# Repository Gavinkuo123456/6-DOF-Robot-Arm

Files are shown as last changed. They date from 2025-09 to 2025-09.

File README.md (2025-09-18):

# Cost-Effective 6 DOF robotic arm

A cost-effective 6-degree-of-freedom robotic arm offering both precision and a strong load capacity for its price range.

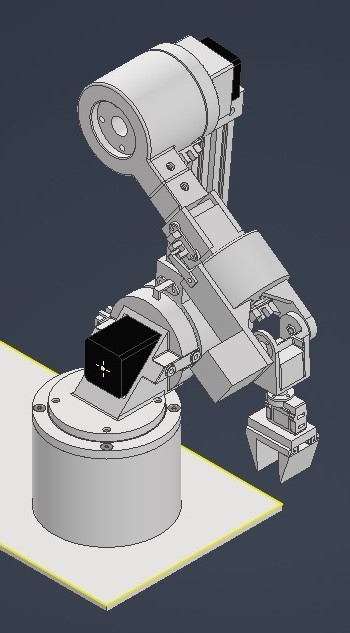
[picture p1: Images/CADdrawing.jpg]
Robot Arm CAD


## 🤖 Overview

This project features a fully functional 6-DOF robotic arm that combines:
- **3D printed mechanical components** for cost-effective construction
- **Stepper motor actuation** for precise positioning
- **Powerfull motor controller** for driving high-torque motors with precise control
- **Arduino-based control system** for accessibility and expandability
- **Open-loop control** for simplicity, reliability and easy maintenance

## ✨ Features

- **6 Degrees of Freedom**: Full spatial movement capability
- **Stepper Motor Control**: Precise angular positioning
- **3D Printable Design**: Accessible manufacturing with standard FDM printers
- **Arduino Compatible**: Easy programming and customization
- **Open Source**: Complete design files and code available
- **standard hardware**: Easy assembly and easy to find online

## 📋 Specifications

| Parameter | Value |
|---|---|
| Degrees of Freedom | 6 |
| Motor Type | Stepper Motors |
| Control System | Arduino-based |
| Control Method | Open-loop |
| Construction | 3D Printed + Hardware |
| Workspace | ? |
| Payload Capacity | ? |
| Repeatability | ✅ |

## 🛠️ Hardware Requirements

### Electronics
- **Arduino Board** Arduino mega 2560
- **Stepper Motor Drivers** TMC2209 × 3 , LM542 x 3
- **Stepper Motors**
   - **Joint 1** NEMA23x56
   - **Joint 2** NEMA17x60 with 1:50 planetary gearbox
   - **Joint 3** NEMA17x48 with 1:27 planetary gearbox
   - **Joint 4** NEMA11x34 with 1:20 planetary gearbox
   - **Joint 5** NEMA 14x40
   - **Joint 6** NEMA11x34
- **Power Supply** 24V 50W
- **Jumper Wires** and **Breadboard/PCB**
- **Limit Switches** optical endstop x 6

# WIP below

### Mechanical Components
- **3D Printed Parts** (see `/mechanical` folder)
- **Bearings** (608ZZ or similar)
- **Screws and Fasteners** (M3, M4, M5 bolts and nuts)
- **Timing Belts and Pulleys** (GT2)
- **Linear Rods** (8mm diameter)

### Tools Required
- 3D Printer (FDM, 200×200×200mm minimum build volume)
- Screwdrivers
- Allen keys/Hex keys
- Wire strippers
- Multimeter

## 🔧 Assembly Instructions

### 1. 3D Printing
1. Print all parts from the `/mechanical/stl` folder
2. Recommended print settings:
   - Layer Height: 0.2mm
   - Infill: 20-30%
   - Support: As needed
   - Material: PLA or PETG

### 2. Electronics Assembly
1. Connect stepper motor drivers to Arduino
2. Wire stepper motors to drivers
3. Connect power supply (ensure proper current ratings)
4. Add limit switches if using homing functionality

### 3. Mechanical Assembly
1. Assemble the base joint (Joint 1)
2. Install shoulder joint (Joint 2)
3. Attach upper arm assembly (Joint 3)
4. Mount forearm assembly (Joint 4)
5. Install wrist joints (Joints 5 & 6)
6. Attach end effector mount

Detailed assembly instructions with images available in `/docs/assembly.md`

## 💻 Software Setup

### Prerequisites
- Arduino IDE (latest version)
- Required Libraries:
  - `AccelStepper`
  - `MultiStepper`
  - `Servo` (if using servo gripper)

### Installation
1. Clone this repository:
   ```bash
   git clone https://github.com/Gavinkuo123456/6-DOF-Robot-Arm.git
   cd 6-DOF-Robot-Arm
   ```

2. Open the main Arduino sketch:
   ```
   /arduino/robot_arm_control/robot_arm_control.ino
   ```

3. Install required libraries through Arduino IDE Library Manager

4. Upload the code to your Arduino board

### Configuration
1. Adjust motor parameters in `config.h`
2. Calibrate joint limits and step ratios
3. Set communication baud rate (default: 115200)

## 🎮 Usage

### Basic Control
The robot arm can be controlled through:
- **Serial Commands**: Send position commands via serial monitor
- **G-code**: Basic G-code interpreter for coordinated movements
- **Python Interface**: Use provided Python scripts for advanced control

### Command Examples
```
// Move to joint positions (degrees)
J 45 30 -20 0 45 90

// Move to Cartesian position (mm)
P 200 150 100 0 90 0

// Home all joints
H

// Emergency stop
STOP
```

### Python Control Example
```python
import serial
import time

# Connect to Arduino
arm = serial.Serial('/dev/ttyUSB0', 115200)
time.sleep(2)

# Move to position
arm.write(b'J 0 45 -30 0 45 0\n')
time.sleep(3)

arm.close()
```

## 📊 Kinematics

The robot arm uses standard Denavit-Hartenberg parameters for kinematic calculations. Forward and inverse kinematics algorithms are implemented for position control.

### Joint Configuration
- **Joint 1**: Base rotation (±180°)
- **Joint 2**: Shoulder pitch (±90°)
- **Joint 3**: Elbow pitch (±135°)
- **Joint 4**: Wrist roll (±180°)
- **Joint 5**: Wrist pitch (±90°)
- **Joint 6**: Wrist yaw (±180°)

## 📁 Project Structure

```
6-DOF-Robot-Arm/
├── arduino/                 # Arduino code
│   ├── robot_arm_control/   # Main control sketch
│   ├── libraries/           # Custom libraries
│   └── examples/            # Example sketches
├── mechanical/              # 3D models and drawings
│   ├── stl/                # STL files for printing
│   ├── cad/                # Original CAD files
│   └── assembly/           # Assembly drawings
├── software/               # PC software and utilities
│   ├── python/             # Python control scripts
│   ├── matlab/             # MATLAB simulation
│   └── gui/                # Graphical interface
├── docs/                   # Documentation
│   ├── assembly.md         # Assembly instructions
│   ├── calibration.md      # Calibration guide
│   └── troubleshooting.md  # Common issues
├── images/                 # Project images
└── README.md              # This file
```

## 🔍 Troubleshooting

### Common Issues
1. **Motors not moving**: Check wiring and power supply
2. **Inaccurate positioning**: Calibrate steps per degree
3. **Communication errors**: Verify baud rate and connections
4. **Mechanical binding**: Check assembly and lubrication

See `/docs/troubleshooting.md` for detailed solutions.

## 🚀 Future Enhancements

- [ ] Closed-loop control with encoders
- [ ] Vision system integration
- [ ] ROS compatibility
- [ ] Mobile app control
- [ ] Advanced path planning
- [ ] Machine learning integration
- [ ] Multi-arm coordination

## 🤝 Contributing

Contributions are welcome! Please feel free to submit pull requests, report bugs, or suggest improvements.

1. Fork the repository
2. Create a feature branch (`git checkout -b feature/amazing-feature`)
3. Commit your changes (`git commit -m 'Add some amazing feature'`)
4. Push to the branch (`git push origin feature/amazing-feature`)
5. Open a Pull Request

## 📝 License

This project is licensed under the MIT License - see the [LICENSE](LICENSE) file for details.

## 👨‍💻 Author

**Gavin Kuo** - [Gavinkuo123456](https://github.com/Gavinkuo123456)

## 🙏 Acknowledgments

- Arduino community for libraries and support
- 3D printing community for design inspiration
- Robotics researchers for kinematic algorithms
- Open-source contributors

## 📞 Support

If you have questions or need help:
- Open an [Issue](https://github.com/Gavinkuo123456/6-DOF-Robot-Arm/issues)
- Check the [Documentation](./docs/)
- Join the discussion in [Discussions](https://github.com/Gavinkuo123456/6-DOF-Robot-Arm/discussions)

---

**⭐ Star this repository if you find it helpful!**




Made with ❤️ for the robotics community

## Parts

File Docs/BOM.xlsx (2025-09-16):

名稱 | 數量 | 價格 | 網址 |  | 列印件 | 重量(g) | 列印時間
平面軸承12cm | 1 | 358 | https://www.ruten.com.tw/item/show?22412077561142 |  | 關節一基座 | 168.75 | 11:57:00
57x56mm步進馬達 | 1 | 540 | https://www.ruten.com.tw/item/show?22446200583860 |  | 關節二基座 | 88 | 5:40:00
42x60mm步進馬達1:50減速機 | 1 | 811 | https://www.ruten.com.tw/item/show?22449367276945 |  | 關節二移動件 | 77 | 5:10:00
6009軸承 | 2 | 532 | https://www.ruten.com.tw/item/show?22513075948398 |  | 關節三基座 | 65 | 4:53:00
Z21-內徑8*外徑18脹緊套 | 2 | 482 | https://www.ruten.com.tw/item/show?22527034233935 |  | 關節三移動件 | 82 | 5:17:00
42x48mm步進馬達1:27減速機 | 1 | 631 | https://www.ruten.com.tw/item/show?22449367276945 |  | 關節四基座 | 30 | 2:31:00
28x33步進馬達1:20減速機 | 1 | 680 | https://www.ruten.com.tw/item/show?22449367276945 |  | 關節四馬達蓋 | 8 | 0:00:00
圓法蘭18mm | 2 | 316 | https://www.ruten.com.tw/item/show?22511904533779 |  | 關節四移動件(五基座) | 51 | 4:07:00
28x34mm步進馬達 | 1 | 584 | https://www.ruten.com.tw/item/show?22529233061690 |  | 關節六基座 | 10 | 0:58:00
6007軸承 | 1 | 146 | https://www.ruten.com.tw/item/show?22513075948398 |  | 夾爪基座 | 4 | 0:31:00
5mm聯軸器 | 1 | 50 | https://www.ruten.com.tw/item/show?21822082042595 |  | 夾爪滑槽 | 7.5 | 1:00:00
35x40mm步進馬達 | 1 | 261 | https://www.ruten.com.tw/item/show?22534632849356 |  | 夾爪手指 | 6.6 | 0:46:00
MG90S伺服馬達 | 1 | 70 |  | 光華 | 夾爪齒輪 | 0.76 | 0:06:00
光學限位開關 | 6 | 216 | https://www.ruten.com.tw/item/show?22534602360418
LM542步進驅動器(大馬達用) | 3 | 1173 | https://www.ruten.com.tw/item/show?22324952210619
Arduino Mega2560 | 1 | 508 | https://www.ruten.com.tw/item/show?22422643706143
TMC2209步進驅動器(小馬達用) | 3 | 444 | https://www.ruten.com.tw/item/show?22326111341624
CNC shield | 1 | 46 | https://www.ruten.com.tw/item/show?22412100171865
萬用板 | 1 |  |  | 光華
杜邦排針 | 數排 |  |  | 光華
杜邦裸線 | 四種顏色數條 |  |  | 光華
杜邦4pin接頭 | 數個 |  |  | 光華
M5螺絲+羅母 | 大量 |  | https://www.ruten.com.tw/store/goodsforyou2014/
M4螺絲+羅母 | 大量 |  | https://www.ruten.com.tw/store/goodsforyou2014/ |  |  | 598.61
M3螺絲+羅母 | 大量 |  | https://www.ruten.com.tw/store/goodsforyou2014/
鋁擠型2020 | 三根
 |  | 7848

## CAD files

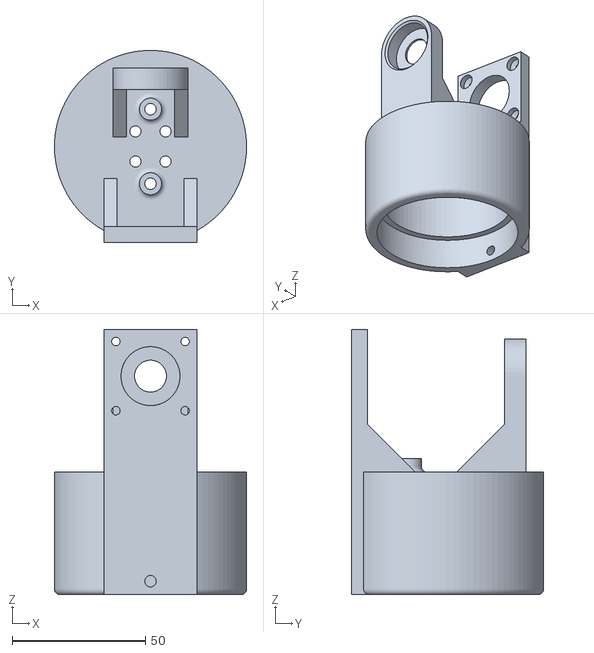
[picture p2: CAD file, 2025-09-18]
3D-model/3D print and Laser cut file/j4 moving part.stl
72.1 x 72.1 x 99.5

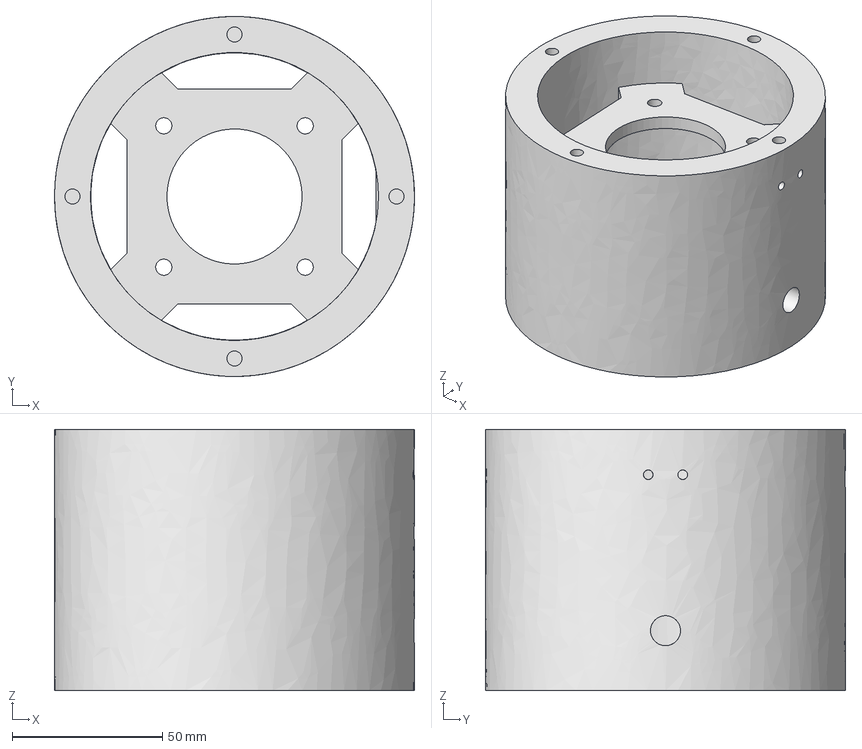
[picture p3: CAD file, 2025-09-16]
3D-model/robot armT 2(CAD file)/j1 57 mount CNC.igs
120.0 x 120.0 x 87.1 mm

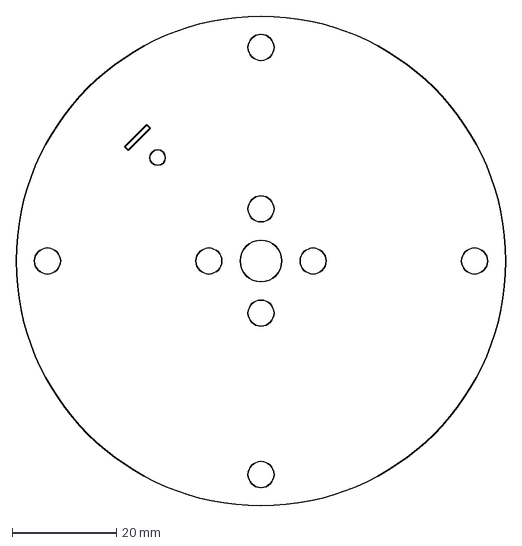
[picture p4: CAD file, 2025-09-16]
3D-model/robot armT 2/3dp/j1 plate lz.dxf
94.0 x 94.0 mm

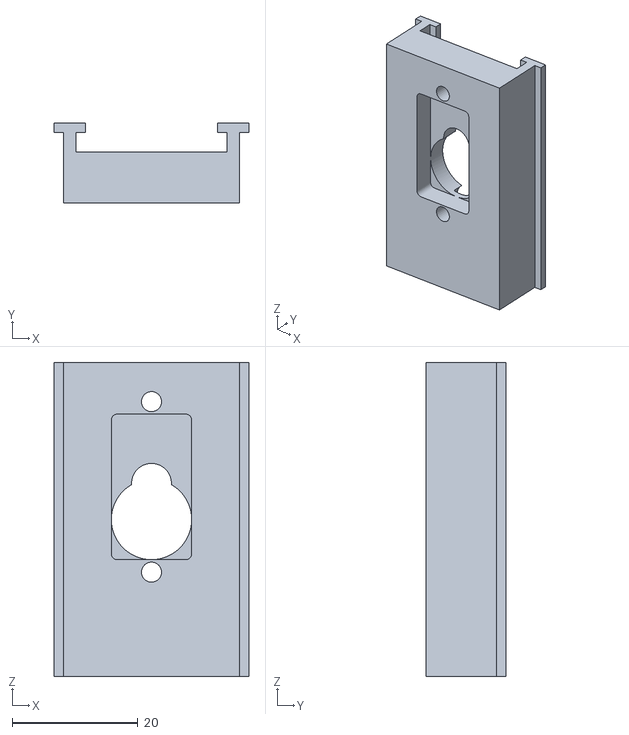
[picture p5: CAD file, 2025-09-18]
3D-model/3D print and Laser cut file/sg90 claw mount.stl
31.0 x 12.7 x 50.0

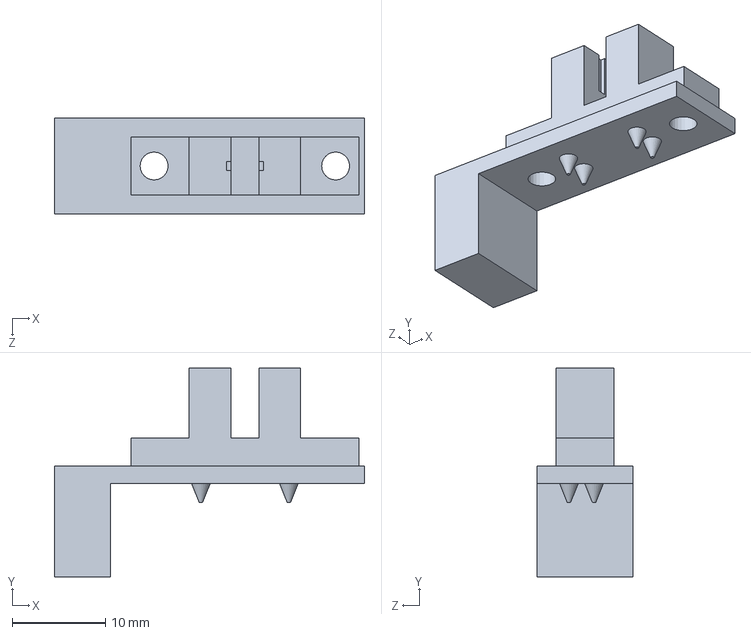
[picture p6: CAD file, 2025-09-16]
3D-model/robot armT 2(CAD file)/optik_limit_switch.SLDPRT
33.3 x 22.4 x 10.3 mm

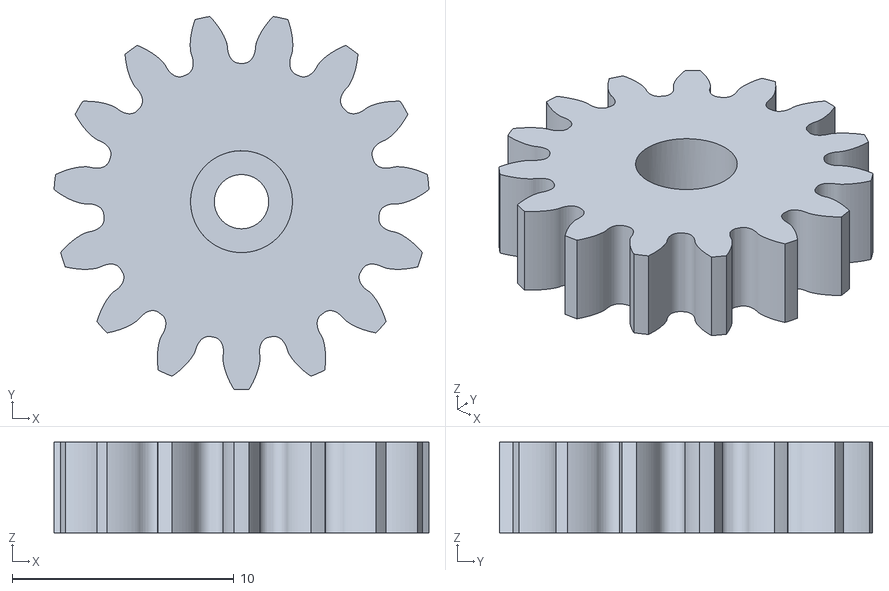
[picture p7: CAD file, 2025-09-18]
3D-model/3D print and Laser cut file/sg90 claw gear m1.stl
16.9 x 16.8 x 4.10

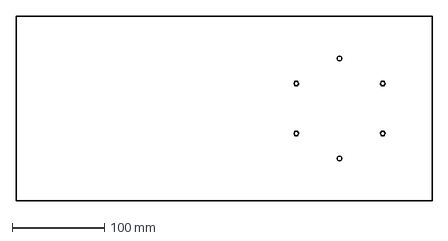
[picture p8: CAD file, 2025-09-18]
3D-model/3D print and Laser cut file/base plate laser cut.dxf
450.0 x 200.0 mm

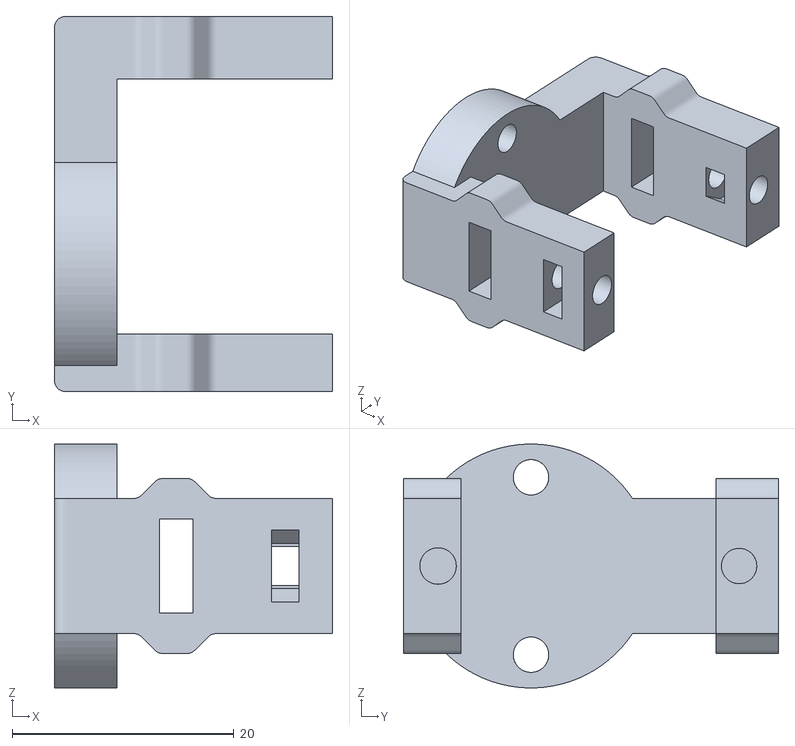
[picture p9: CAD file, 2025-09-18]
3D-model/3D print and Laser cut file/sg90 claw v2 conector.stl
25.1 x 33.8 x 22.0

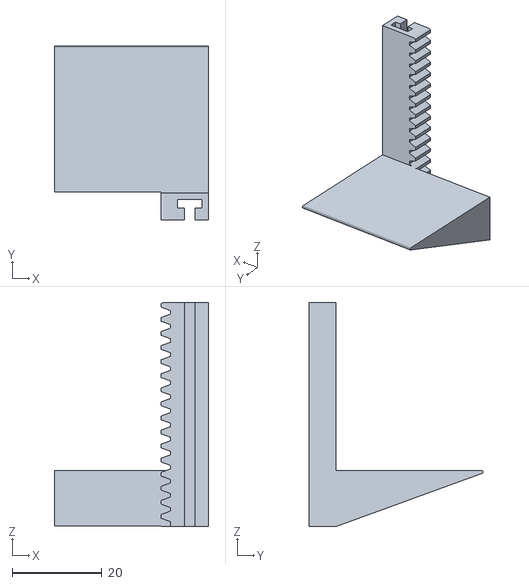
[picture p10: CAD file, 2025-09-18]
3D-model/3D print and Laser cut file/sg90 claw finger long.stl
34.4 x 38.9 x 50.0

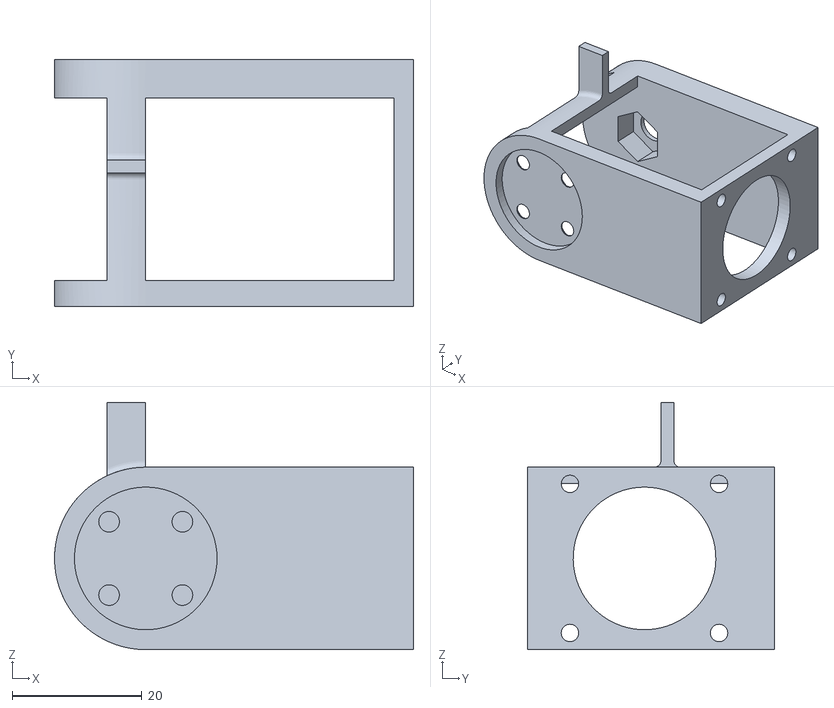
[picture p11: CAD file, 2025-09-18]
3D-model/3D print and Laser cut file/j6 motor mount .stl
55.4 x 38.2 x 38.2

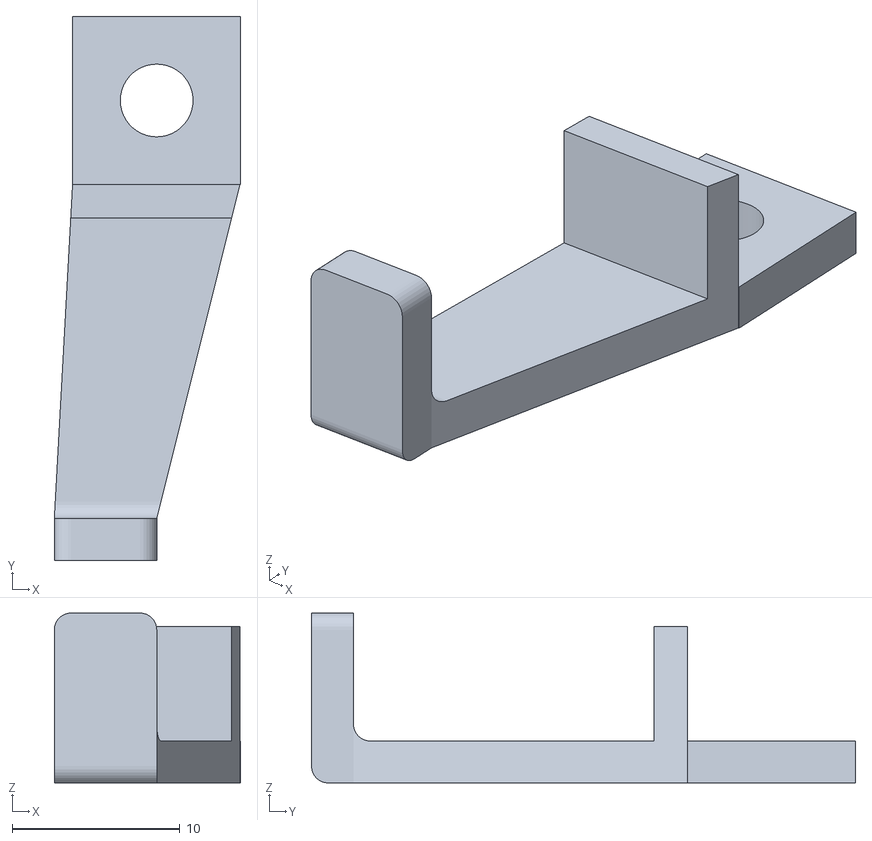
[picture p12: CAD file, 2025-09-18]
3D-model/3D print and Laser cut file/j4 endstop blocker.stl
11.1 x 32.4 x 10.1

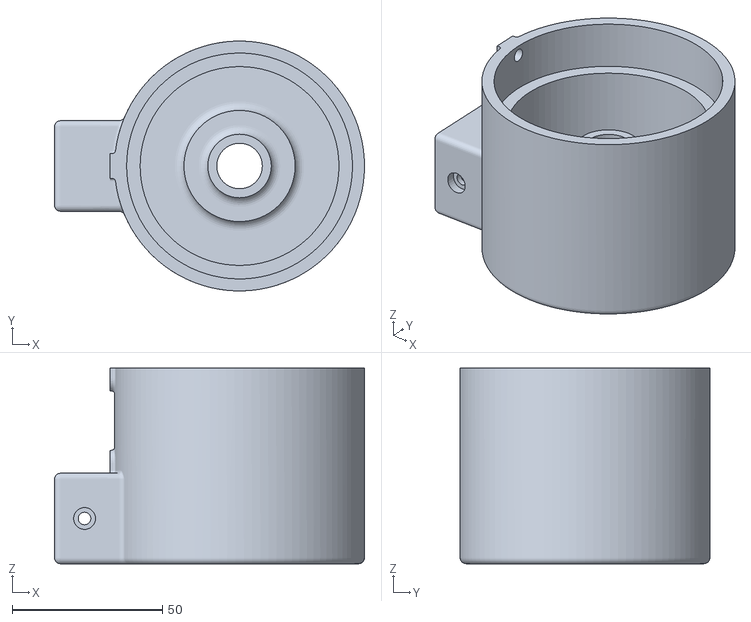
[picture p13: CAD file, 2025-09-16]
3D-model/3D print and Laser cut file/j3 moving part.stl
103.2 x 83.1 x 65.1

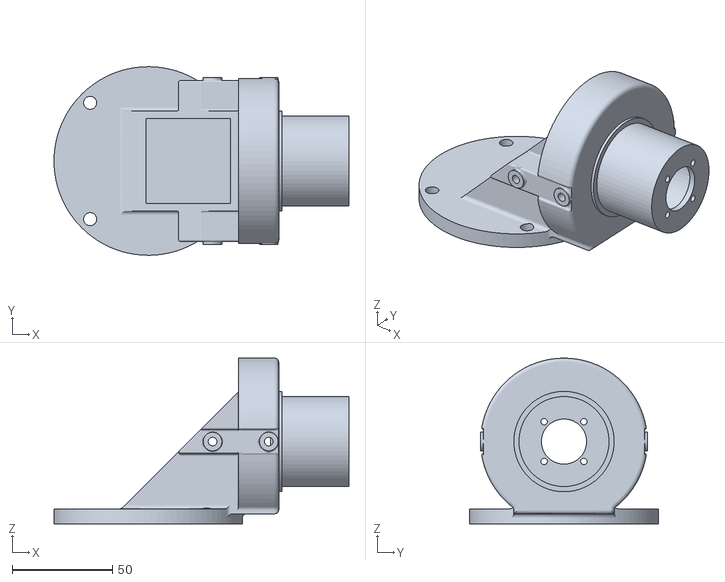
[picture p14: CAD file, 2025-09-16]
3D-model/3D print and Laser cut file/j2 42 motor mount.stl
147.0 x 94.0 x 82.5

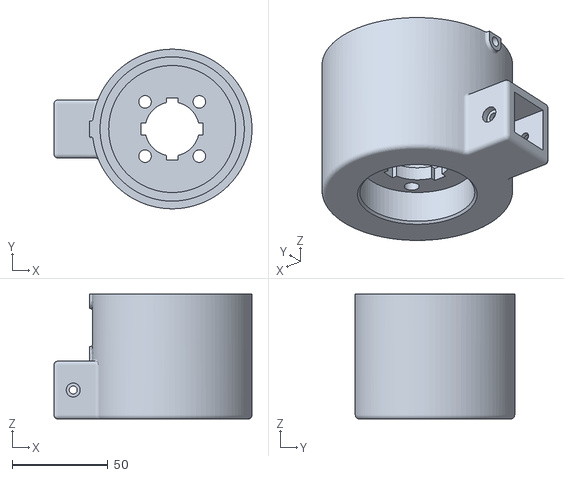
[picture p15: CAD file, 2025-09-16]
3D-model/3D print and Laser cut file/j3 moving part option3.stl
103.2 x 83.1 x 65.1

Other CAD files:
3D-model/3D print and Laser cut file/j2 moving part option2.stl
3D-model/3D print and Laser cut file/j3 endstop blocker.stl
3D-model/3D print and Laser cut file/j2 endstop blocker.stl
3D-model/3D print and Laser cut file/j4 motor mount.stl
3D-model/3D print and Laser cut file/j1 57 mount.stl
3D-model/3D print and Laser cut file/j1 endstop block v2.stl
3D-model/3D print and Laser cut file/j4 motor mount cover.stl
3D-model/robot armT 2(CAD file)/18mm hub.ipt
3D-model/robot armT 2(CAD file)/28stepper27.ipt
3D-model/robot armT 2(CAD file)/35x40 stepper.ipt
3D-model/robot armT 2(CAD file)/5mm axle hub.ipt
3D-model/robot armT 2(CAD file)/6mm axle hub.ipt
3D-model/robot armT 2(CAD file)/8 mm hub.ipt
3D-model/robot armT 2(CAD file)/8mm axle mount.ipt
3D-model/robot armT 2(CAD file)/9G Servo Motor SG90.ipt
3D-model/robot armT 2(CAD file)/BS 4168 - M5 x 16(7).ipt
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

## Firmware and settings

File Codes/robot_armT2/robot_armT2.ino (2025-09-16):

#include <Wire.h>
#include <Servo.h>
#include <AccelStepper.h>
#include <math.h>

// Define stepper pins
#define ASTEP_PIN 48  // Step pin
#define ADIR_PIN 50   // Direction pin
#define AENABLE 52
#define BSTEP_PIN 44  // Step pin
#define BDIR_PIN 46   // Direction pin
#define CSTEP_PIN 40  // Step pin
#define CDIR_PIN 42   // Direction pin
#define DSTEP_PIN 2   // Step pin
#define DDIR_PIN 5    // Direction pin
#define ESTEP_PIN 3   // Step pin
#define EDIR_PIN 6
#define FSTEP_PIN 4
#define FDIR_PIN 7
#define ENABLE 8

#define Aendstop 43
#define Bendstop 41
#define Cendstop 39
#define Dendstop 37
#define Eendstop 35
#define emergbtn 53

const int SLAVE_ADDRESS = 1;
char incomingByte = 0;
char ji2cindex;
bool i2cIN = 0;

String i2cC = "";

float alocation = 0;
float blocation = 0;
float clocation = 0;
float dlocation = 0;
float elocation = 0;
float flocation = 0;
float clawlocation = 0;

const float agear = 1;
const float bgear = 50;
const float cgear = 27;
const float dgear = 20;
const float egear = 1;
const float fgear = 1;
const float steppower = 4.4;  // 1/(360/steps/rev)
const float radtoang = 57.295;


// Steps per revolution for the motor
const float speed = 900;
const float maxspeed = 800;

const float accel = 500;
const float stepsPerRevolution = 1600;
// Microstepping multiplier (1, 2, 4, 8, 16, or 32)

// AccelStepper instance in driver mode
AccelStepper stepperA(AccelStepper::DRIVER, ASTEP_PIN, ADIR_PIN);
AccelStepper stepperB(AccelStepper::DRIVER, BSTEP_PIN, BDIR_PIN);
AccelStepper stepperC(AccelStepper::DRIVER, CSTEP_PIN, CDIR_PIN);
AccelStepper stepperD(AccelStepper::DRIVER, DSTEP_PIN, DDIR_PIN);
AccelStepper stepperE(AccelStepper::DRIVER, ESTEP_PIN, EDIR_PIN);
AccelStepper stepperF(AccelStepper::DRIVER, FSTEP_PIN, FDIR_PIN);
Servo claw;

static const int DOF = 6;
static const float alpha_[DOF] = { -1.57f, 0.00f, 1.57f, -1.57f, 1.57f, 0.00f };     // radians
static const float a_[DOF] = { 0.000f, 252.625f, 0.000f, 0.000f, 0.000f, 0.000f };   // mm
static const float d_[DOF] = { 136.1f, 0.0f, 0.0f, 214.6f, 0.0f, 129.471f };         // mm
static const float theta_off_[DOF] = { 0.00f, -1.57f, 1.57f, 0.00f, 0.00f, 0.00f };  // radians

// IK settings
static const int MAX_ITERS = 120;     // iterations cap
static const float DAMPING = 0.02f;   // lambda for DLS (radians & mm units)
static const float POS_TOL = 0.5f;    // mm
static const float ROT_TOL = 0.005f;  // rad (~0.29 deg)
// ---------------------------------------------------------------------------------
// Math helpers
// ---------------------------------------------------------------------------------
struct Vec3 {
  float x, y, z;
};

static inline float clampf(float x, float lo, float hi) {
  return x < lo ? lo : (x > hi ? hi : x);
}

static inline void mat4Mul(const float A[16], const float B[16], float C[16]) {
  for (int r = 0; r < 4; r++) {
    for (int c = 0; c < 4; c++) {
      float s = 0;
      for (int k = 0; k < 4; k++) s += A[r * 4 + k] * B[k * 4 + c];
      C[r * 4 + c] = s;
    }
  }
}

static inline void mat4Copy(const float S[16], float D[16]) {
  for (int i = 0; i < 16; i++) D[i] = S[i];
}

static inline void mat4FromDH(float a, float alpha, float d, float theta, float T[16]) {
  float ct = cosf(theta), st = sinf(theta);
  float ca = cosf(alpha), sa = sinf(alpha);
  T[0] = ct;
  T[1] = -st * ca;
  T[2] = st * sa;
  T[3] = a * ct;
  T[4] = st;
  T[5] = ct * ca;
  T[6] = -ct * sa;
  T[7] = a * st;
  T[8] = 0;
  T[9] = sa;
  T[10] = ca;
  T[11] = d;
  T[12] = 0;
  T[13] = 0;
  T[14] = 0;
  T[15] = 1;
}

static inline void mat4ExtractRPY_ZYX(const float T[16], float &rx, float &ry, float &rz) {
  // ZYX intrinsic (yaw Z, pitch Y, roll X). Using rotation matrix R = T[0..10].
  const float r00 = T[0], r01 = T[1], r02 = T[2];
  const float r10 = T[4], r11 = T[5], r12 = T[6];
  const float r20 = T[8], r21 = T[9], r22 = T[10];
  float pitch = asinf(-clampf(r20, -1.0f, 1.0f));
  float roll, yaw;
  if (fabsf(r20) < 0.9999f) {
    roll = atan2f(r21, r22);
    yaw = atan2f(r10, r00);
  } else {
    // Gimbal-close case: use alternative
    roll = 0.0f;
    yaw = atan2f(-r01, r11);
  }
  rx = roll;
  ry = pitch;
  rz = yaw;
}

static inline void rpyZYX_to_R(float rx, float ry, float rz, float R[9]) {
  // rx=roll(X), ry=pitch(Y), rz=yaw(Z)
  float cx = cosf(rx), sx = sinf(rx);
  float cy = cosf(ry), sy = sinf(ry);
  float cz = cosf(rz), sz = sinf(rz);
  // R = Rz(rz)*Ry(ry)*Rx(rx)
  R[0] = cz * cy;
  R[1] = cz * sy * sx - sz * cx;
  R[2] = cz * sy * cx + sz * sx;
  R[3] = sz * cy;
  R[4] = sz * sy * sx + cz * cx;
  R[5] = sz * sy * cx - cz * sx;
  R[6] = -sy;
  R[7] = cy * sx;
  R[8] = cy * cx;
}

static inline void R_to_axisAngle(const float R[9], float axis[3], float &angle) {
  float tr = R[0] + R[4] + R[8];
  float c = (tr - 1.0f) * 0.5f;
  c = clampf(c, -1.0f, 1.0f);
  angle = acosf(c);
  if (angle < 1e-6f) {
    axis[0] = axis[1] = axis[2] = 0;
    angle = 0;
    return;
  }
  float denom = 2.0f * sinf(angle);
  axis[0] = (R[7] - R[5]) / denom;
  axis[1] = (R[2] - R[6]) / denom;
  axis[2] = (R[3] - R[1]) / denom;
}

// ---------------------------------------------------------------------------------
// Forward Kinematics
// ---------------------------------------------------------------------------------
static void fk(const float q[DOF], float T[16]) {
  float Ti[16], Tacc[16];
  // Init to identity
  for (int i = 0; i < 16; i++) Tacc[i] = (i % 5 == 0) ? 1.0f : 0.0f;
  for (int i = 0; i < DOF; i++) {
    float theta = q[i] + theta_off_[i];
    mat4FromDH(a_[i], alpha_[i], d_[i], theta, Ti);
    float Tnew[16];
    mat4Mul(Tacc, Ti, Tnew);
    mat4Copy(Tnew, Tacc);
  }
  mat4Copy(Tacc, T);
}

// ---------------------------------------------------------------------------------
// Jacobian (geometric) for 6R arm
// ---------------------------------------------------------------------------------
static void jacobian(const float q[DOF], float J[6 * DOF]) {
  float Tacc[16];
  // identity
  for (int i = 0; i < 16; i++) Tacc[i] = (i % 5 == 0) ? 1.0f : 0.0f;

  float origins[DOF + 1][3];
  float zaxes[DOF + 1][3];

  // base frame
  origins[0][0] = 0;
  origins[0][1] = 0;
  origins[0][2] = 0;
  zaxes[0][0] = 0;
  zaxes[0][1] = 0;
  zaxes[0][2] = 1;

  // accumulate frames
  for (int i = 0; i < DOF; i++) {
    float Ti[16];
    float theta = q[i] + theta_off_[i];
    mat4FromDH(a_[i], alpha_[i], d_[i], theta, Ti);
    float Tnew[16];
    mat4Mul(Tacc, Ti, Tnew);
    mat4Copy(Tnew, Tacc);

    origins[i + 1][0] = Tacc[3];
    origins[i + 1][1] = Tacc[7];
    origins[i + 1][2] = Tacc[11];

    zaxes[i + 1][0] = Tacc[2];
    zaxes[i + 1][1] = Tacc[6];
    zaxes[i + 1][2] = Tacc[10];
  }

  float pe[3] = { origins[DOF][0], origins[DOF][1], origins[DOF][2] };

  for (int i = 0; i < DOF; i++) {
    float zi[3] = { zaxes[i][0], zaxes[i][1], zaxes[i][2] };
    float pi[3] = { origins[i][0], origins[i][1], origins[i][2] };
    float r[3] = { pe[0] - pi[0], pe[1] - pi[1], pe[2] - pi[2] };
    // cross(zi, r)
    float jv[3] = { zi[1] * r[2] - zi[2] * r[1], zi[2] * r[0] - zi[0] * r[2], zi[0] * r[1] - zi[1] * r[0] };

    J[0 * DOF + i] = jv[0];
    J[1 * DOF + i] = jv[1];
    J[2 * DOF + i] = jv[2];
    J[3 * DOF + i] = zi[0];
    J[4 * DOF + i] = zi[1];
    J[5 * DOF + i] = zi[2];
  }
}

// Multiply 6x6 with 6x1: y = A*x
static inline void mat6x6_mul_vec(const float A[36], const float x[6], float y[6]) {
  for (int r = 0; r < 6; r++) {
    float s = 0;
    for (int c = 0; c < 6; c++) s += A[r * 6 + c] * x[c];
    y[r] = s;
  }
}

// Build normal matrix A = J*J^T + (lambda^2) I (6x6) and compute its inverse via adjugate/Gauss-Jordan (simple, not super-optimized)
// Returns false if singular.
static bool invert6x6(const float A[36], float invA[36]) {
  // Augment [A | I] and perform Gauss-Jordan
  float M[6][12];
  for (int r = 0; r < 6; r++) {
    for (int c = 0; c < 6; c++) M[r][c] = A[r * 6 + c];
    for (int c = 0; c < 6; c++) M[r][6 + c] = (r == c) ? 1.0f : 0.0f;
  }
  for (int i = 0; i < 6; i++) {
    // pivot
    int piv = i;
    float maxA = fabsf(M[i][i]);
    for (int r = i + 1; r < 6; r++) {
      float v = fabsf(M[r][i]);
      if (v > maxA) {
        maxA = v;
        piv = r;
      }
    }
    if (maxA < 1e-8f) return false;
    if (piv != i) {
      for (int c = 0; c < 12; c++) {
        float tmp = M[i][c];
        M[i][c] = M[piv][c];
        M[piv][c] = tmp;
      }
    }
    // normalize row
    float diag = M[i][i];
    for (int c = 0; c < 12; c++) M[i][c] /= diag;
    // eliminate
    for (int r = 0; r < 6; r++)
      if (r != i) {
        float f = M[r][i];
        if (f != 0) {
          for (int c = 0; c < 12; c++) M[r][c] -= f * M[i][c];
        }
      }
  }
  // extract inv
  for (int r = 0; r < 6; r++)
    for (int c = 0; c < 6; c++) invA[r * 6 + c] = M[r][6 + c];
  return true;
}

// Compute error twist between current T(q) and desired pose (x,y,z, rpy_ZYX)
static void poseError(const float Tcurr[16], const float p_des[3], const float rpy_des[3], float e[6]) {
  // position error
  e[0] = p_des[0] - Tcurr[3];
  e[1] = p_des[1] - Tcurr[7];
  e[2] = p_des[2] - Tcurr[11];
  // orientation error via axis-angle of R_err = R_des * R_curr^T
  float Rcurr[9] = { Tcurr[0], Tcurr[1], Tcurr[2], Tcurr[4], Tcurr[5], Tcurr[6], Tcurr[8], Tcurr[9], Tcurr[10] };
  float Rdes[9];
  rpyZYX_to_R(rpy_des[0], rpy_des[1], rpy_des[2], Rdes);
  // R_err = Rdes * Rcurr^T
  float Rct[9] = { Rcurr[0], Rcurr[3], Rcurr[6], Rcurr[1], Rcurr[4], Rcurr[7], Rcurr[2], Rcurr[5], Rcurr[8] };
  float Rerr[9];
  for (int r = 0; r < 3; r++)
    for (int c = 0; c < 3; c++) {
      float s = 0;
      for (int k = 0; k < 3; k++) s += Rdes[r * 3 + k] * Rct[k * 3 + c];
      Rerr[r * 3 + c] = s;
    }
  float axis[3];
  float ang;
  R_to_axisAngle(Rerr, axis, ang);
  e[3] = axis[0] * ang;
  e[4] = axis[1] * ang;
  e[5] = axis[2] * ang;  // small-angle rotation vector
}

// Damped Least Squares IK: returns true if converged, q is updated in-place
static bool ik_solve(float q[DOF], const float p_des[3], const float rpy_des[3]) {
  for (int iter = 0; iter < MAX_ITERS; ++iter) {
    // FK and error
    float Tcurr[16];
    fk(q, Tcurr);
    float e[6];
    poseError(Tcurr, p_des, rpy_des, e);

    float pos_err = sqrtf(e[0] * e[0] + e[1] * e[1] + e[2] * e[2]);
    float rot_err = sqrtf(e[3] * e[3] + e[4] * e[4] + e[5] * e[5]);
    if (pos_err < POS_TOL && rot_err < ROT_TOL) return true;

    // Jacobian
    float J[6 * DOF];
    jacobian(q, J);

    // A = J*J^T + λ^2 I (6x6)
    float A[36] = { 0 };
    for (int r = 0; r < 6; r++) {
      for (int c = 0; c < 6; c++) {
        float s = 0;
        for (int k = 0; k < DOF; k++) s += J[r * DOF + k] * J[c * DOF + k];
        A[r * 6 + c] = s;
      }
      A[r * 6 + r] += (DAMPING * DAMPING);
    }
    float invA[36];
    if (!invert6x6(A, invA)) return false;

    // y = invA * e
    float y[6];
    mat6x6_mul_vec(invA, e, y);

    // dq = J^T * y
    float dq[DOF];
    for (int i = 0; i < DOF; i++) {
      float s = 0;
      for (int r = 0; r < 6; r++) s += J[r * DOF + i] * y[r];
      dq[i] = s;
    }

    // step size limiting (simple clipping)
    const float MAX_STEP = 0.2f;  // rad per iter (or mm-equivalent via Jacobian mapping)
    for (int i = 0; i < DOF; i++) dq[i] = clampf(dq[i], -MAX_STEP, MAX_STEP);

    for (int i = 0; i < DOF; i++) q[i] += dq[i];
  }
  return false;  // not converged
}

// ---------------------------------------------------------------------------------
// Serial parsing helpers
// ---------------------------------------------------------------------------------
static bool readLine(String &out) {
  if (!Serial.available()) return false;
  out = Serial.readStringUntil('\n');
  out.trim();
  return out.length() > 0;
}

static int splitTokens(const String &s, String tokens[], int maxTok) {
  int n = 0;
  int i = 0;
  while (i < s.length() && n < maxTok) {
    while (i < s.length() && isspace(s[i])) i++;
    if (i >= s.length()) break;
    int j = i;
    while (j < s.length() && !isspace(s[j])) j++;
    tokens[n++] = s.substring(i, j);
    i = j;
  }
  return n;
}

static bool parseFloats(String tokens[], int start, int count, float *out) {
  for (int i = 0; i < count; i++) {
    char *endptr;
    String t = tokens[start + i];
    out[i] = t.toFloat();  // Arduino String has toFloat()
  }
  return true;
}

static void printArray(const float *v, int n) {
  for (int i = 0; i < n; i++) {
    if (i) Serial.print(' ');
    // print with 6 decimals
    Serial.print(v[i], 6);
  }
  Serial.println();
}
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
void loop() {
  if (digitalRead(emergbtn) == HIGH) {
    motorzero();
  }
  stepperA.run();
  stepperB.run();
  stepperC.run();
  stepperD.run();
  stepperE.run();
  stepperF.run();
  String line;
  if (!readLine(line)) return;  // no blocking
  String tok[20];
  int n = splitTokens(line, tok, 20);
  if (n <= 0) return;

  if (tok[0] == "FK" && n == 1 + DOF) {
    float q[DOF];
    parseFloats(tok, 1, DOF, q);
    float T[16];
    fk(q, T);
    float rx, ry, rz;
    mat4ExtractRPY_ZYX(T, rx, ry, rz);
    float out[6] = { T[3], T[7], T[11], rx, ry, rz };
    printArray(out, 6);
  } else if (tok[0] == "IK" && (n == 1 + 6 || n == 1 + 6 + DOF)) {
    float p[3], rpy[3];
    parseFloats(tok, 1, 3, p);
    parseFloats(tok, 4, 3, rpy);
    float q[DOF] = { 0, 0, 1.57, 0, 0, 0 };
    if (n == 1 + 6 + DOF) parseFloats(tok, 1 + 6, DOF, q);

    bool ok = ik_solve(q, p, rpy);
    if (!ok) Serial.print(F("#WARN: not fully converged -> "));
    printArray(q, DOF);
    motormove(q);
  } else if (tok[0] == "HELP") {
    Serial.println(F("FK q1 q2 q3 q4 q5 q6"));
    Serial.println(F("IK X Y Z RX RY RZ [q1 q2 q3 q4 q5 q6]"));
  } else if (tok[0] == "jm") {
    resetspeed();
    alocation = tok[1].toFloat();
    blocation = tok[2].toFloat();
    clocation = tok[3].toFloat();
    dlocation = tok[4].toFloat();
    elocation = tok[5].toFloat();
    flocation = tok[6].toFloat();
    if (alocation <= 90 && alocation >= -90) {
      Serial.print("A motor move = ");
      Serial.println(alocation);
      stepperA.moveTo(alocation * steppower);
    }
    if (blocation <= 90 && blocation >= -90) {
      Serial.print("B motor move = ");
      Serial.println(blocation);
      stepperB.moveTo(blocation * bgear * steppower);
    }
    if (clocation <= 160 && clocation >= -160) {
      Serial.print("C motor move = ");
      Serial.println(clocation);
      stepperC.moveTo(-1 * clocation * cgear * steppower);
    }
    if (dlocation <= 170 && dlocation >= -170) {
      Serial.print("D motor move = ");
      Serial.println(dlocation);
      stepperD.moveTo(-1 * dlocation * dgear * steppower);
    }
    if (elocation <= 90 && elocation >= -90) {
      Serial.print("E motor move = ");
      Serial.println(elocation);
      stepperE.moveTo(elocation * egear * steppower);
    }
    if (flocation <= 180 && flocation >= -180) {
      Serial.print("F motor move = ");
      Serial.println(flocation);
      stepperF.moveTo(-1 * flocation * fgear * steppower);
    }
  } else if (tok[0] == "zro") {
    motorzero();
  } else if (tok[0] == "clm") {
    clawlocation = tok[1].toFloat();
    if (clawlocation <= 180 && clawlocation >= 0) {
      Serial.print("claw motor move = ");
      Serial.println(clawlocation);
      claw.write(clawlocation);
    }
  } else {
    Serial.println(F("#ERR: bad command. Use HELP"));
  }
  if (i2cIN == true) {
    I2Crunmotor();
  }
}

void resetspeed() {
  stepperA.setMaxSpeed(maxspeed * agear);
  stepperA.setAcceleration(accel * agear);
  stepperB.setMaxSpeed(maxspeed * bgear);
  stepperB.setAcceleration(accel * bgear);
  stepperC.setMaxSpeed(maxspeed * cgear);
  stepperC.setAcceleration(accel * cgear);
  stepperD.setMaxSpeed(maxspeed * dgear);
  stepperD.setAcceleration(accel * dgear);
  stepperE.setMaxSpeed(maxspeed * egear);
  stepperE.setAcceleration(accel * egear);
  stepperF.setMaxSpeed(maxspeed * fgear);
  stepperF.setAcceleration(accel * fgear);
}
void receiveEvent() {//I2C received, copy from void loop
  String receivedstr = "";
  while (Wire.available()) {
    char inByte;
    inByte = Wire.read();
    receivedstr += inByte;
  }
  Serial.println(receivedstr);
  String tok[20];
  int n = splitTokens(receivedstr, tok, 20);
  if (n <= 0) return;

  if (tok[0] == "FK" && n == 1 + DOF) {
    float q[DOF];
    parseFloats(tok, 1, DOF, q);
    float T[16];
    fk(q, T);
    float rx, ry, rz;
    mat4ExtractRPY_ZYX(T, rx, ry, rz);
    float out[6] = { T[3], T[7], T[11], rx, ry, rz };
    printArray(out, 6);
  } else if (tok[0] == "IK" && (n == 1 + 6 || n == 1 + 6 + DOF)) {
    float p[3], rpy[3];
    parseFloats(tok, 1, 3, p);
    parseFloats(tok, 4, 3, rpy);
    float q[DOF] = { 0, 0, 1.57, 0, 0, 0 };
    if (n == 1 + 6 + DOF) parseFloats(tok, 1 + 6, DOF, q);

    bool ok = ik_solve(q, p, rpy);
    if (!ok) Serial.print(F("#WARN: not fully converged -> "));
    printArray(q, DOF);
    motormove(q);
  } else if (tok[0] == "HELP") {
    Serial.println(F("FK q1 q2 q3 q4 q5 q6"));
    Serial.println(F("IK X Y Z RX RY RZ [q1 q2 q3 q4 q5 q6]"));
  } else if (tok[0] == "jm") {
    resetspeed();
    alocation = tok[1].toFloat();
    blocation = tok[2].toFloat();
    clocation = tok[3].toFloat();
    dlocation = tok[4].toFloat();
    elocation = tok[5].toFloat();
    flocation = tok[6].toFloat();
    if (alocation <= 90 && alocation >= -90) {
      Serial.print("A motor move = ");
      Serial.println(alocation);
      stepperA.moveTo(alocation * steppower);
    }
    if (blocation <= 90 && blocation >= -90) {
      Serial.print("B motor move = ");
      Serial.println(blocation);
      stepperB.moveTo(blocation * bgear * steppower);
    }
    if (clocation <= 160 && clocation >= -160) {
      Serial.print("C motor move = ");
      Serial.println(clocation);
      stepperC.moveTo(-1 * clocation * cgear * steppower);
    }
    if (dlocation <= 170 && dlocation >= -170) {
      Serial.print("D motor move = ");
      Serial.println(dlocation);
      stepperD.moveTo(-1 * dlocation * dgear * steppower);
    }
    if (elocation <= 90 && elocation >= -90) {
      Serial.print("E motor move = ");
      Serial.println(elocation);
      stepperE.moveTo(elocation * egear * steppower);
    }
    if (flocation <= 180 && flocation >= -180) {
      Serial.print("F motor move = ");
      Serial.println(flocation);
      stepperF.moveTo(-1 * flocation * fgear * steppower);
    }
  } else if (tok[0] == "zro") {
    motorzero();
  } else if (tok[0] == "clm") {
    clawlocation = tok[1].toFloat();
    if (clawlocation <= 180 && clawlocation >= 0) {
      Serial.print("claw motor move = ");
      Serial.println(clawlocation);
      claw.write(clawlocation);
    }
  } else {
    Serial.println(F("#ERR: bad command. Use HELP"));
  }
}

void I2Crunmotor() {
  Serial.print("joint ");
  Serial.print(ji2cindex);
  Serial.print(",run:");
  Serial.print(i2cC);
  int angle = i2cC.toInt();
  switch (ji2cindex) {
    case 'a':
      if (angle <= 180 && angle >= 0) {
        stepperA.moveTo(angle * steppower);
      }
      break;
    case 'b':
      if (angle <= 180 && angle >= 0) {
        stepperB.moveTo(angle * bgear * steppower);
      }
      break;
    case 'c':
      if (angle <= 180 && angle >= 0) {
        stepperC.moveTo(angle * cgear * steppower);
      }
      break;
    case 'd':
      if (angle <= 180 && angle >= 0) {
      }
      break;
    case 'e':
      if (angle <= 180 && angle >= 0) {
      }
      break;
    case 'f':
      if (angle <= 180 && angle >= 0) {
      }
      break;
    case 'h':
      if (angle <= 180 && angle >= 0) {
        claw.write(angle);
      }
      break;
  }
  i2cIN = false;
  i2cC = "";
}
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

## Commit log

2025-09-16 first upload
    [18mm hub.ipt, 28stepper27.0001.ipt, 28stepper27.ipt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]
2025-09-18 small change
    [main assembly.0126.iam, main assembly.0127.iam, main assembly.iam]
2025-09-18 add img
    [j2 endstop blocker.0006.ipt, j2 endstop blocker.ipt, j2 moving part option2.0002.ipt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]
